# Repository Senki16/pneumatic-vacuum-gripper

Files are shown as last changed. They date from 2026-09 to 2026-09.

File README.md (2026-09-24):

# Pneumatic Vacuum Gripper for Robotic Arm

Modular vacuum gripper for the **CRP-RA09A-07** robotic arm, driven by a **FESTO VN-10-H** venturi generator with four Ø25 mm bellows suction cups in a cross layout. It handles flat parts up to **500 g** at an operating vacuum of **≥ −0.60 bar**, with real-time vacuum monitoring by an **ESP32** and an **MPX5700** sensor.

Final project (Phase 4) for *Mechanical Design – Methodical Design*, Department of Mechanical Engineering, **Universidad EAFIT** (Medellín, Colombia), May 2026.

<p align="center">
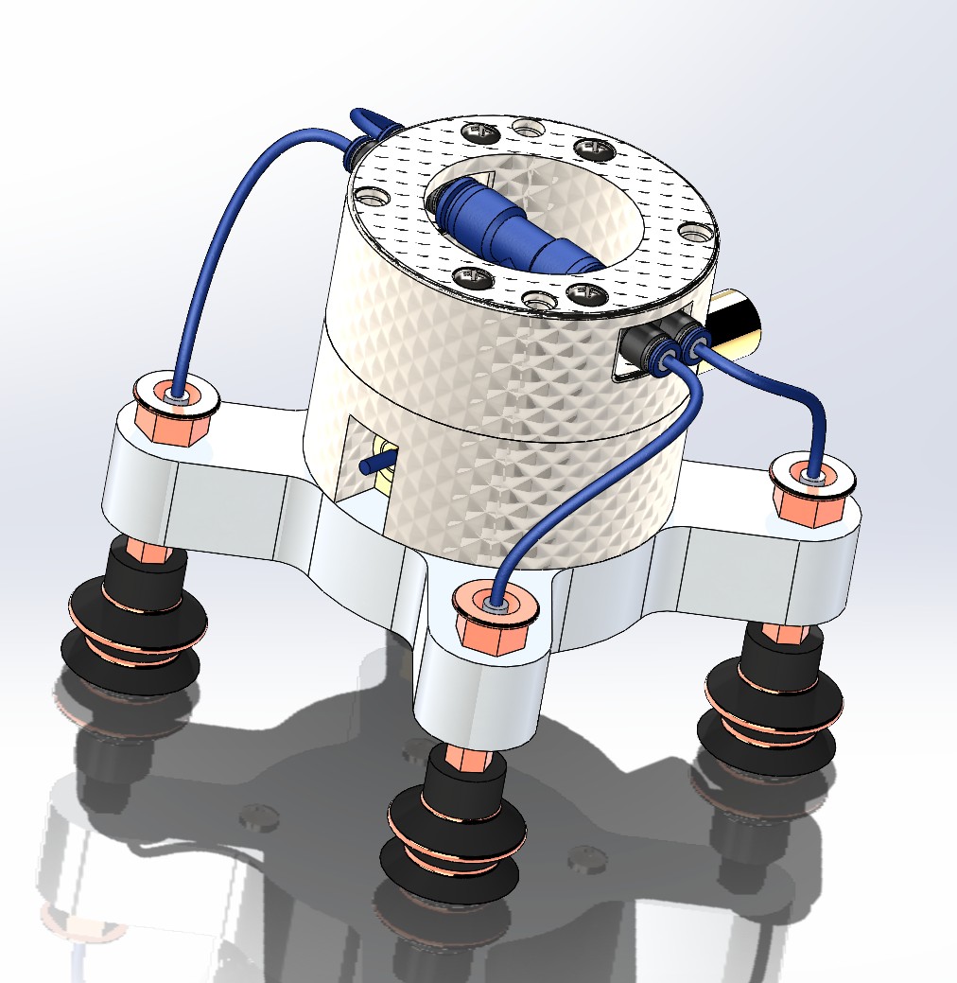
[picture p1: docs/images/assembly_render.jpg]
SolidWorks render of the pneumatic vacuum gripper assembly
  
</p>
<p align="center"><em>SolidWorks assembly: robot coupling, suction cup base, VN-10-H venturi and four Ø25 mm bellows suction cups.</em></p>

---

## Features

- **Structure:** three machined parts in 6061-T6 aluminum (suction cup base, upper coupling, robot coupling), ±0.1 mm tolerance, Ra 3.2 µm surface finish
- **Pneumatics:** FESTO VN-10-H venturi, 4–6 bar supply, 4 × Ø25 mm bellows suction cups, Ø6 mm tubing, T-connector and G1/8 fittings
- **Electronics:** ESP32, MPX5700 vacuum sensor, PNP vacuum switch set to −0.60 bar, LM2596 / AMS1117 regulators
- **Documentation:** 7 illustrated process charts (F1–F7) following ISO 9001:2015 clause 8.5.1, a QFD matrix, a validation plan and a cost analysis

## Test results

All six KPIs passed. Each was measured over at least 10 cycles.

| KPI | Target | Result |
|---|---|---|
| Grip force | ≥ 5 N | **6.2 N** ✅ |
| Positioning accuracy | ≤ 0.5 mm | **0.3 mm** ✅ |
| Repeatability (30 cycles at 5 bar) | ≥ 95 % | **96.7 %** ✅ |
| Response time | ≤ 0.5 s | **0.38 s** ✅ |
| Load capacity | 500 g for ≥ 30 s | **500 g for 36 s** ✅ |
| Operating vacuum | ≥ −0.60 bar | **−0.63 bar** ✅ |

The system also passed a leak test at 4 bar for 60 s with no bubbles.

## Cost

The best scenario (supplier C, using an existing air line) costs **$1,113,170 COP**. That is **34.6 % less** than the original baseline of $1,701,700 COP, with an estimated gross margin of 44.4 %. Details are in [`05_Spreadsheets/Costs`](05_Spreadsheets/Costs).

## Repository structure

```
01_CAD/
  SolidWorks_Assembly/      SolidWorks parts (.SLDPRT) and assemblies (.SLDASM)
  3D_Print_STL/             STL files ready for 3D printing
02_Documentation/           Final report (PDF) and design Q&A
03_Presentations/           PowerPoint and web (HTML) presentations
04_Process_Charts/          Illustrated manufacturing process charts F1–F7
05_Spreadsheets/            QFD, process chart, validation plan
  Costs/                    Cost and feasibility analysis
docs/images/                README images (assembly render)
_duplicates/                Duplicate copies kept for reference
```

## Manufacturing process charts

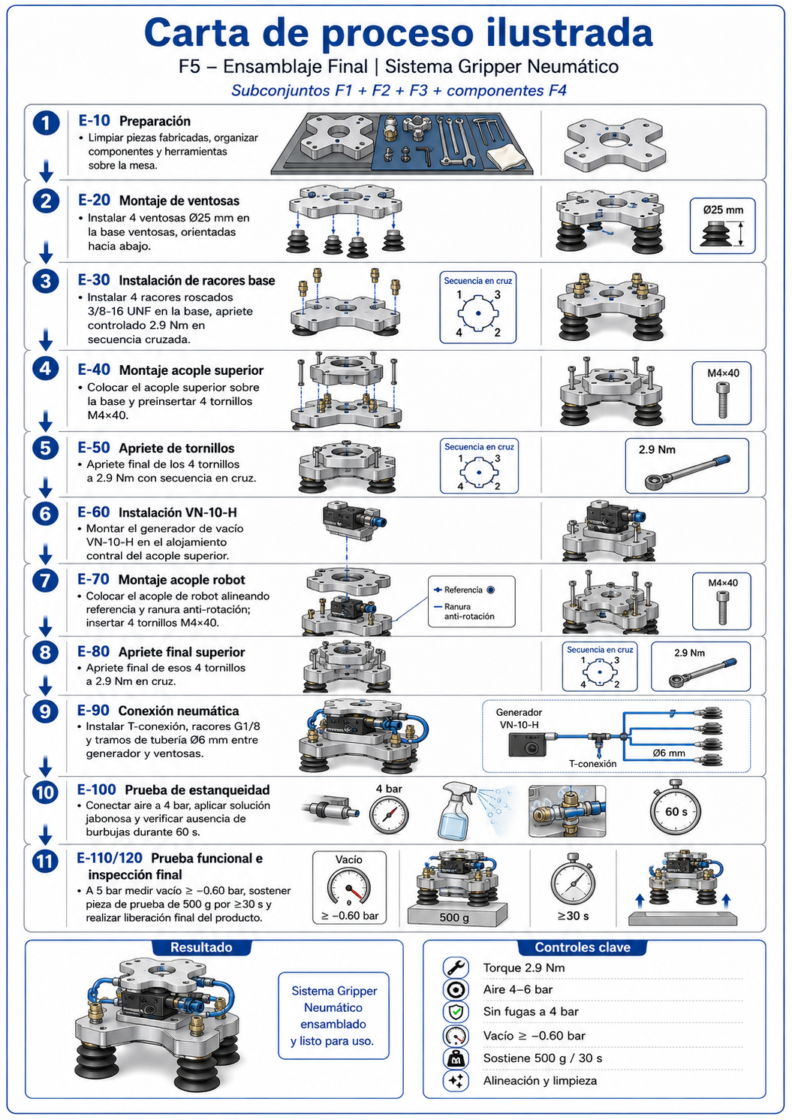
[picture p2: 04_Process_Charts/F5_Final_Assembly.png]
Final assembly process chart


| Chart | Part / stage | Setup (min) | Cycle (min) |
|---|---|---|---|
| [F1](04_Process_Charts/F1_Suction_Cup_Base.png) | Suction cup base – Al 6061-T6 | 90 | 210 |
| [F2](04_Process_Charts/F2_Upper_Coupling.png) | Upper coupling – Al 6061-T6 | 100 | 185 |
| [F3](04_Process_Charts/F3_Robot_Coupling.png) | Robot coupling – Al 6061-T6 | 85 | 145 |
| [F4](04_Process_Charts/F4_Commercial_Components.png) | Commercial components (receiving and prep) | — | — |
| [F5](04_Process_Charts/F5_Final_Assembly.png) | Final assembly and tests | 45 | 110 |
| [F6](04_Process_Charts/F6_Electrical_Assembly.html) | Electrical assembly | 75 | 125 |
| [F7](04_Process_Charts/F7_Pneumatic_Assembly.html) | Pneumatic assembly | — | — |
| | **Total** | **395** | **775** |

## Opening the CAD files

Open `01_CAD/SolidWorks_Assembly/Emsamblaje.SLDASM` in SolidWorks. Keep every part in the same folder so the assembly finds its references. The part files keep their original Spanish names so those references don't break.

## Team — Group 6

- Daniel Ruiz Sandoval
- David Zuluaga Henao
- Santiago Quintero Álvarez
- Julián Guerrero
- Ernesto Enríquez

**Professor:** Ronald Mauricio Martinod Restrepo

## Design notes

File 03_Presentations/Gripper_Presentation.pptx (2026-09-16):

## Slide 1

FASE 4

Prototipo Modelo Funcional
y Evaluación de Diseño

Sistema Gripper Neumático
para Brazo Robótico

Integrantes: Ruiz • Zuluaga • Quintero • Guerrero • Enríquez
Profesor: Ronald M. Martinod Restrepo
Universidad EAFIT — Grupo 6 | 8 de mayo de 2026

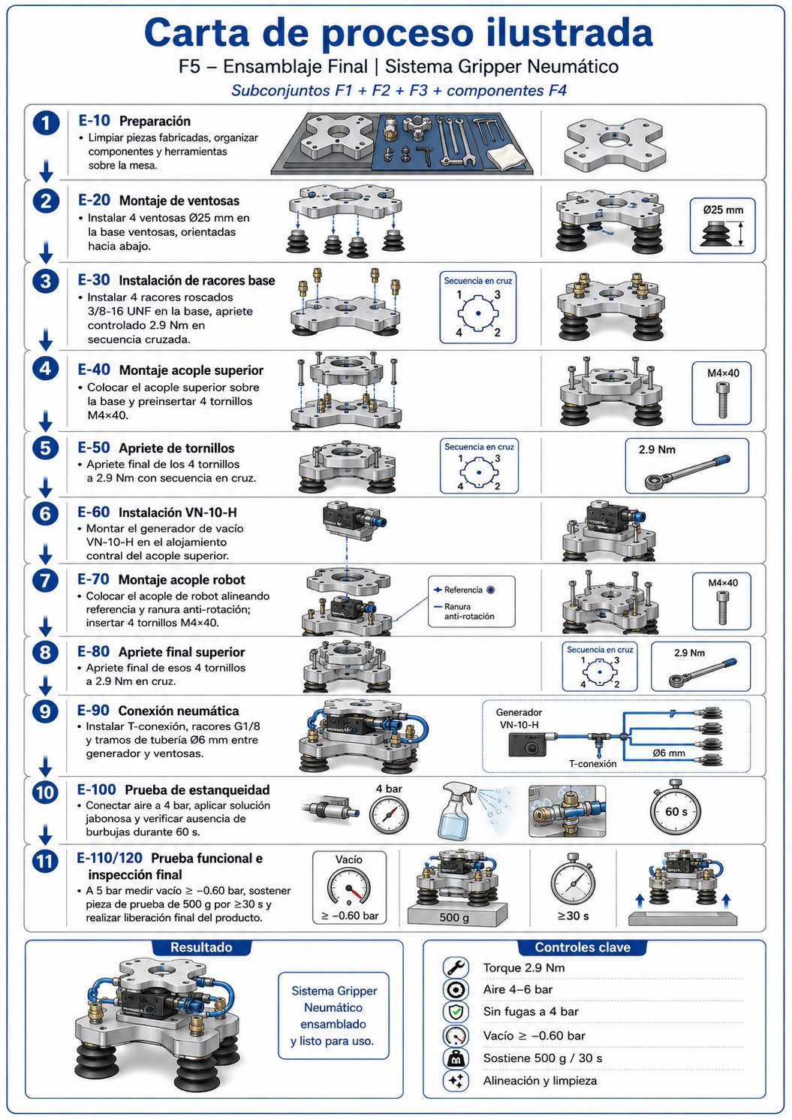
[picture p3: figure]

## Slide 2

Agenda

1. Introducción y Objetivos

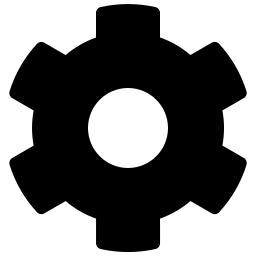
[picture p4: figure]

5. Matriz QFD — Componentes vs. Proceso

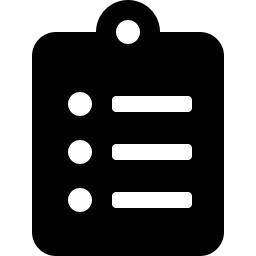
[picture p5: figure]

2. Cartas de Proceso de Fabricación (F1–F7)

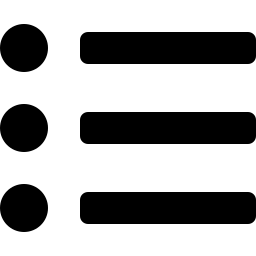
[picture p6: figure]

6. Análisis de Costos

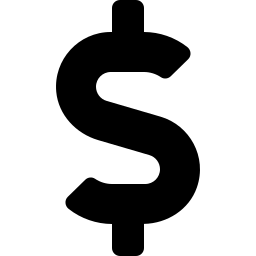
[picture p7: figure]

3. Desarrollo del Prototipo y Calibración

7. Viabilidad Económica

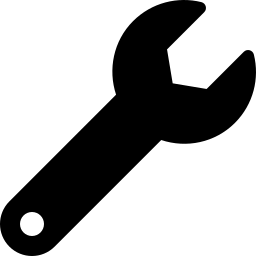
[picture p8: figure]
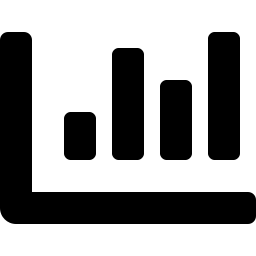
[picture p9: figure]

4. Indicadores de Evaluación y Plan de Pruebas

8. Conclusiones

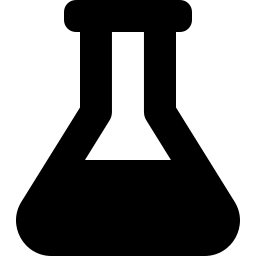
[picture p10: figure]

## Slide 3

01

Introducción
y Objetivos

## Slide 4

Introducción

Contexto
Los grippers son el elemento de interacción directa entre el robot y su entorno. Su diseño debe garantizar precisión, repetibilidad y eficiencia operativa.
Objetivo General
Desarrollar, ensamblar y validar un prototipo funcional de gripper neumático para brazo robótico, evaluando su viabilidad técnica y económica.
Objetivos Específicos
- Definir cartas de proceso de fabricación
- Construir el prototipo (tol. ±0,1 mm, Ra 3,2 µm)
- Ajustar y calibrar el sistema neumático
- Establecer KPIs y plan de pruebas
- Desarrollar matriz QFD
- Analizar costos y viabilidad económica

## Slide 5

02

Cartas de Proceso
de Fabricación F1–F7

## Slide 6

Resumen de Cartas de Proceso

F1

Base Ventosas

Setup / Ciclo:
90 / 210 min

F2

Acople Superior

Setup / Ciclo:
100 / 185 min

F3

Acople de Robot

Setup / Ciclo:
85 / 145 min

F4

Comp. Comerciales

Setup / Ciclo:
— / — min

F5

Ensamblaje Final

Setup / Ciclo:
— / — min

F6

Ensamble Eléctrico

Setup / Ciclo:
75 / 125 min

F7

Ensamble Neumático

Setup / Ciclo:
45 / 110 min

TOTAL: 395 min setup | 775 min ciclo | Norma: ISO 9001:2015 / ASME / DIN ISO 1711-1

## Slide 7

F1 — Base Ventosas

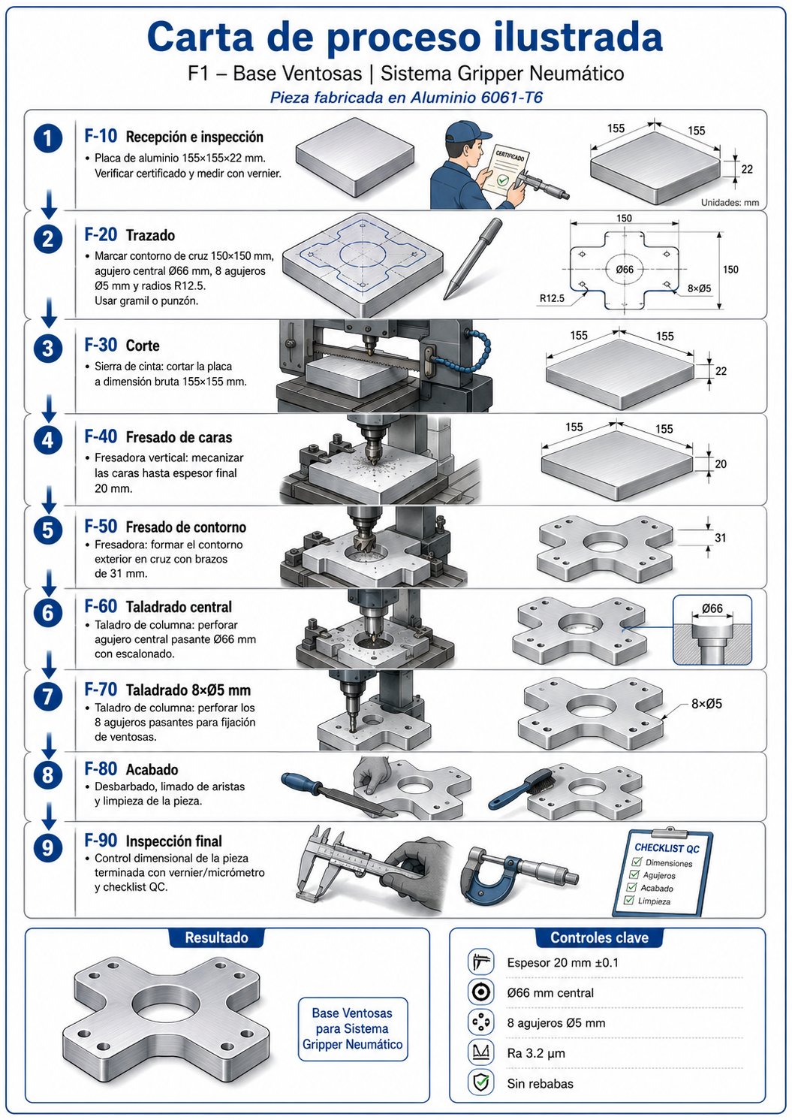
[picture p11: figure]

Al 6061-T6 | 150×150×20 mm | Ø66 central | 8×Ø5 | Ra 3,2 µm

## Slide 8

F2 — Acople Superior

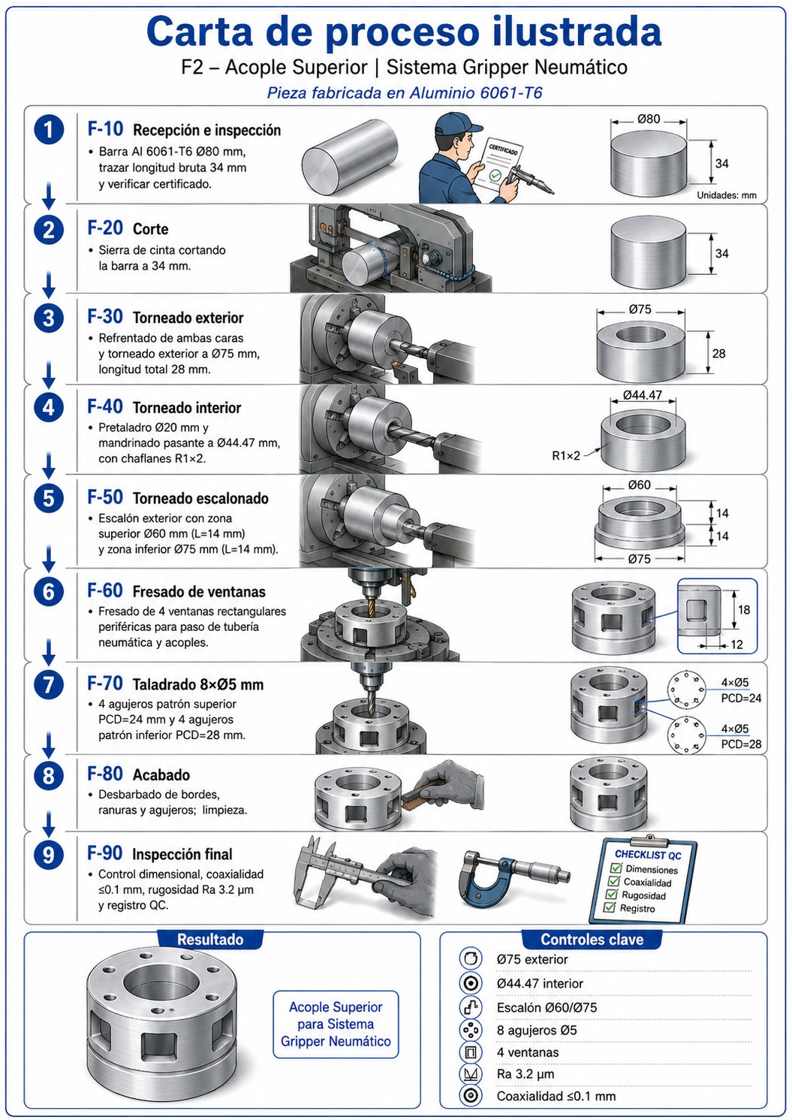
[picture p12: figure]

Al 6061-T6 | Ø75 ext. | Ø44,47 int. | L=28 mm | 8×Ø5

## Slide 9

F3 — Acople de Robot

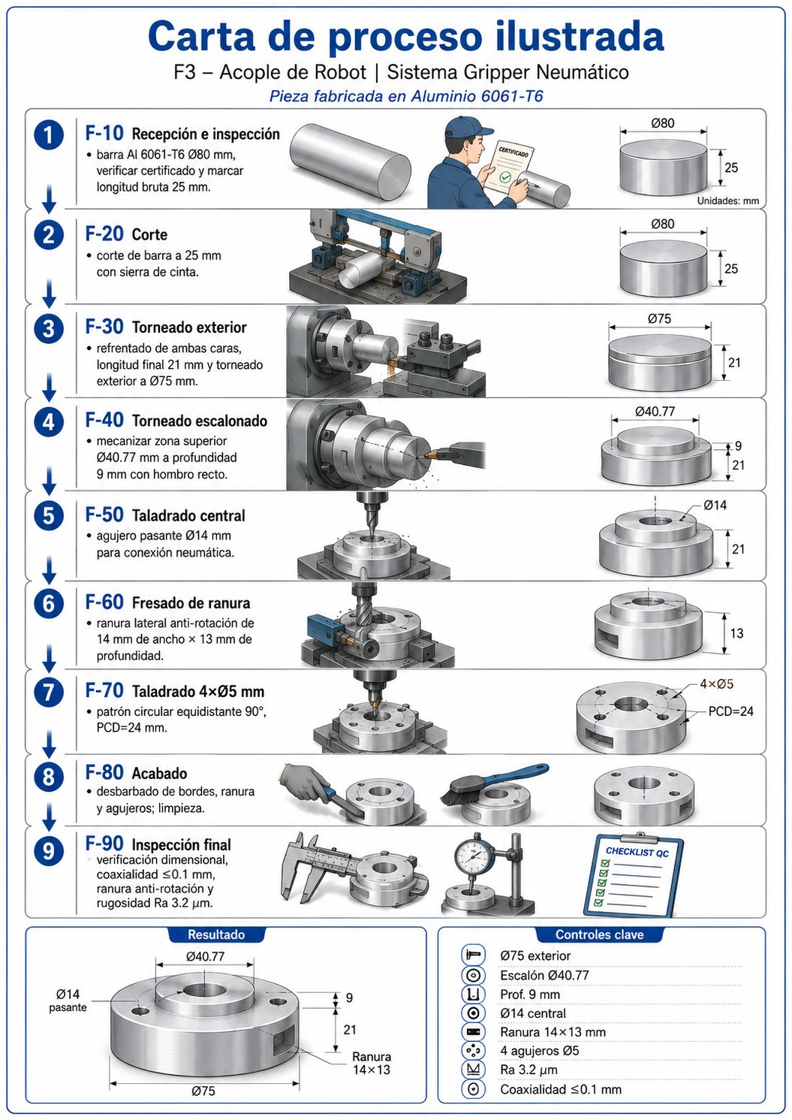
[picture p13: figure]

Al 6061-T6 | Ø75×21 mm | Escalón Ø40,77 | Ranura 14×13 mm

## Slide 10

F4 — Componentes Comerciales

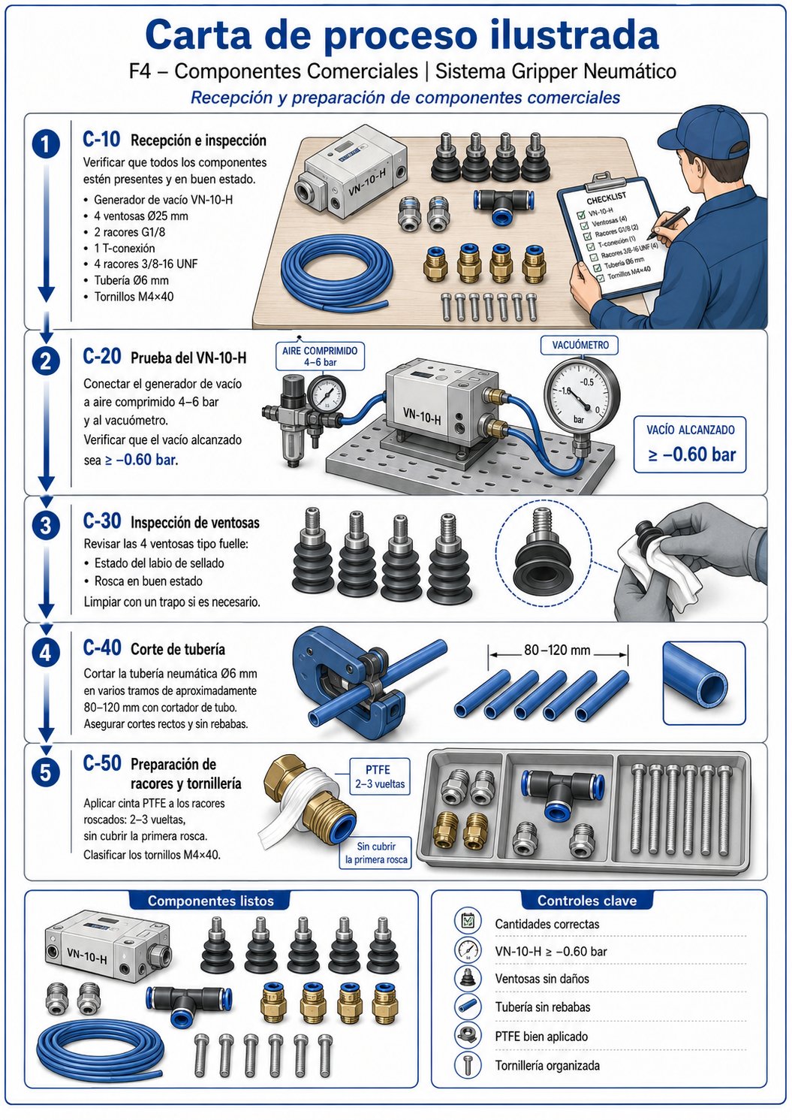
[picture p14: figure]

FESTO VN-10-H | 4× ventosas Ø25 | Cinta PTFE | Prueba vacío ≥ −0,60 bar

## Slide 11

F5 — Ensamblaje Final

Par 2,9 Nm secuencia cruzada | 4 bar/60 s estanqueidad | 500 g/30 s funcional

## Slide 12

F6 — Ensamble Eléctrico

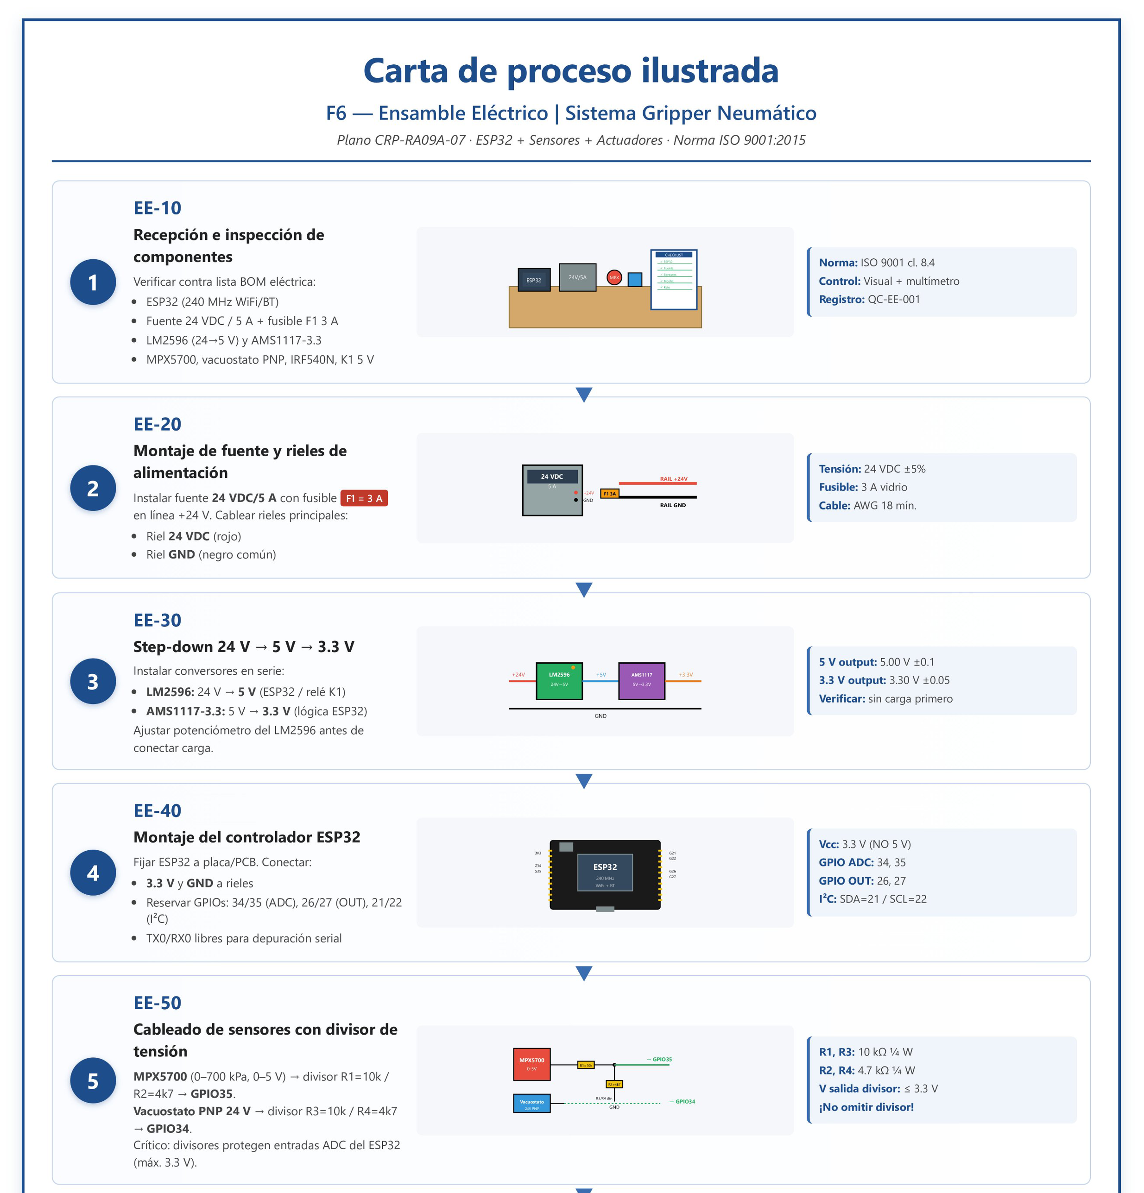
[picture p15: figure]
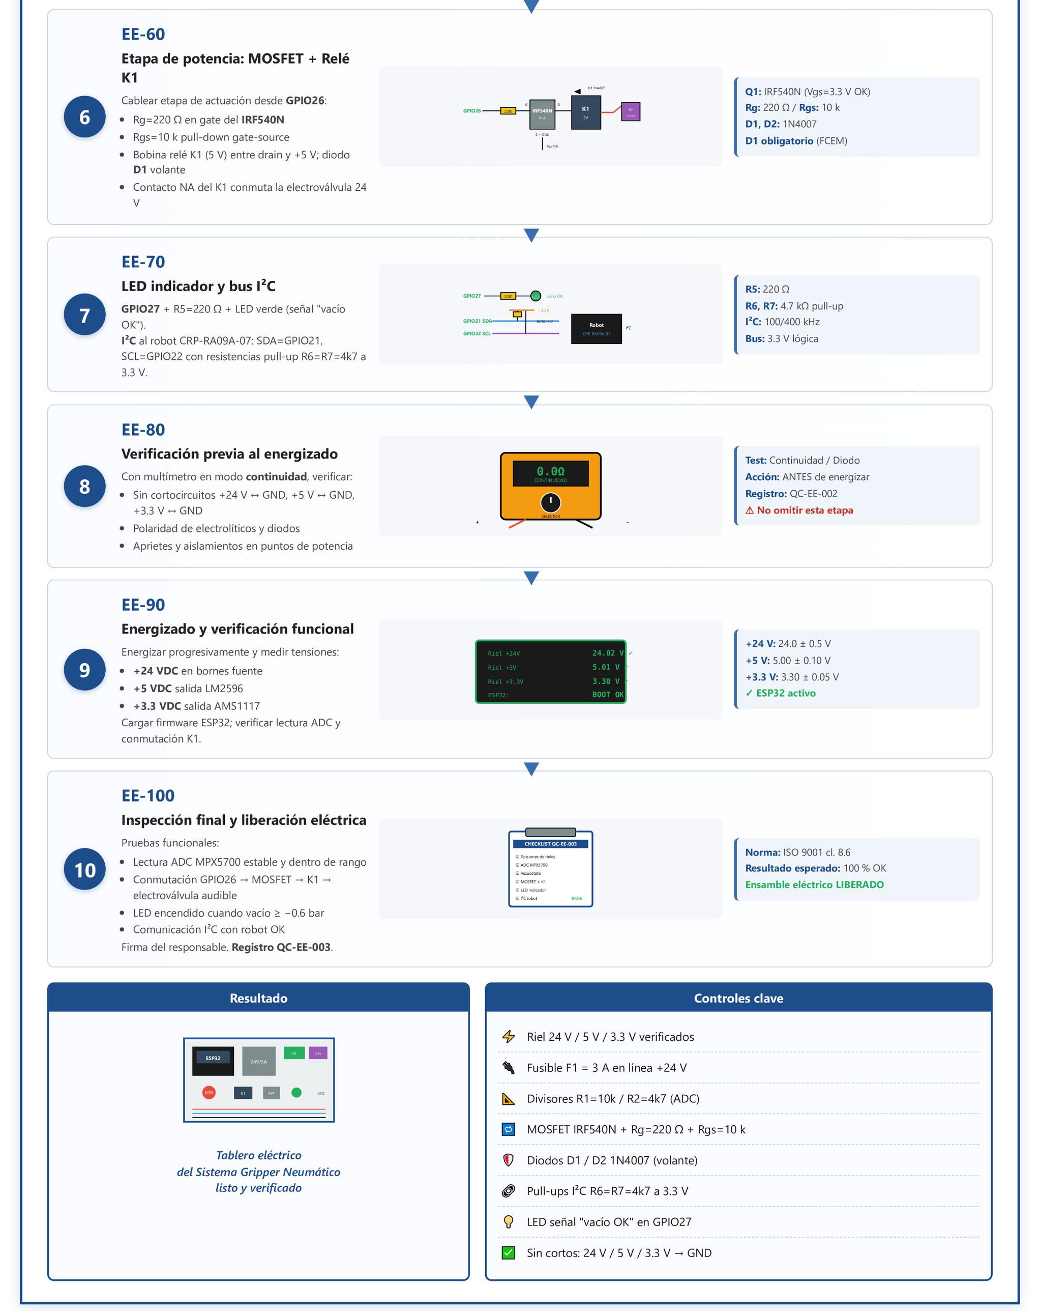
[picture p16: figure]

ESP32 | 24 VDC/5 A | LM2596 | AMS1117 | IRF540N | Relé K1 | Diodos 1N4007

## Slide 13

F7 — Ensamble Neumático

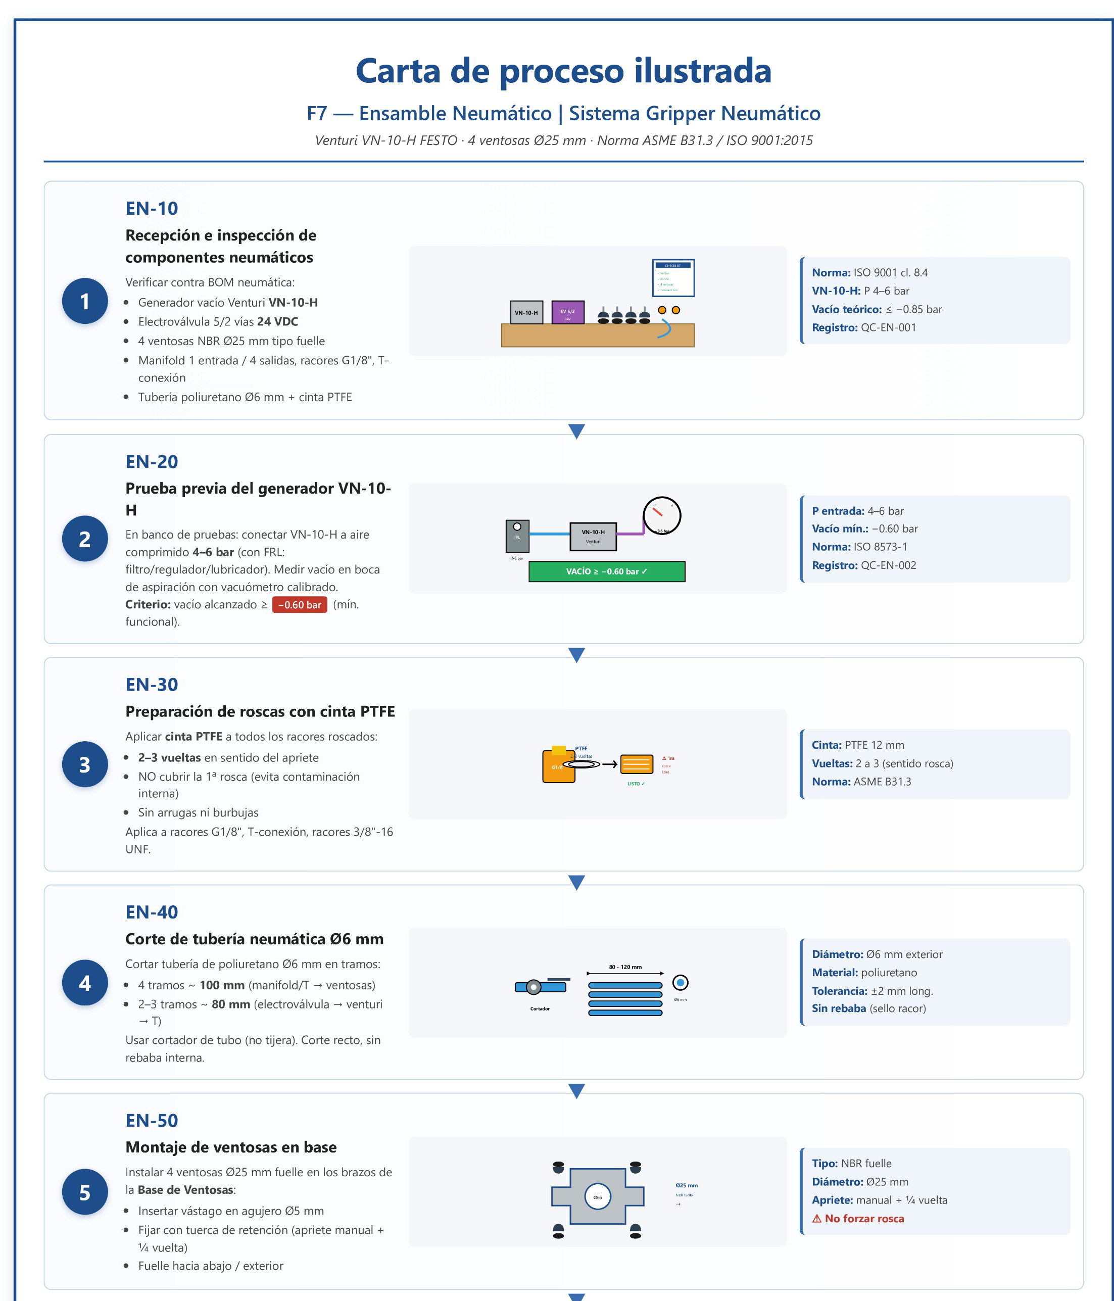
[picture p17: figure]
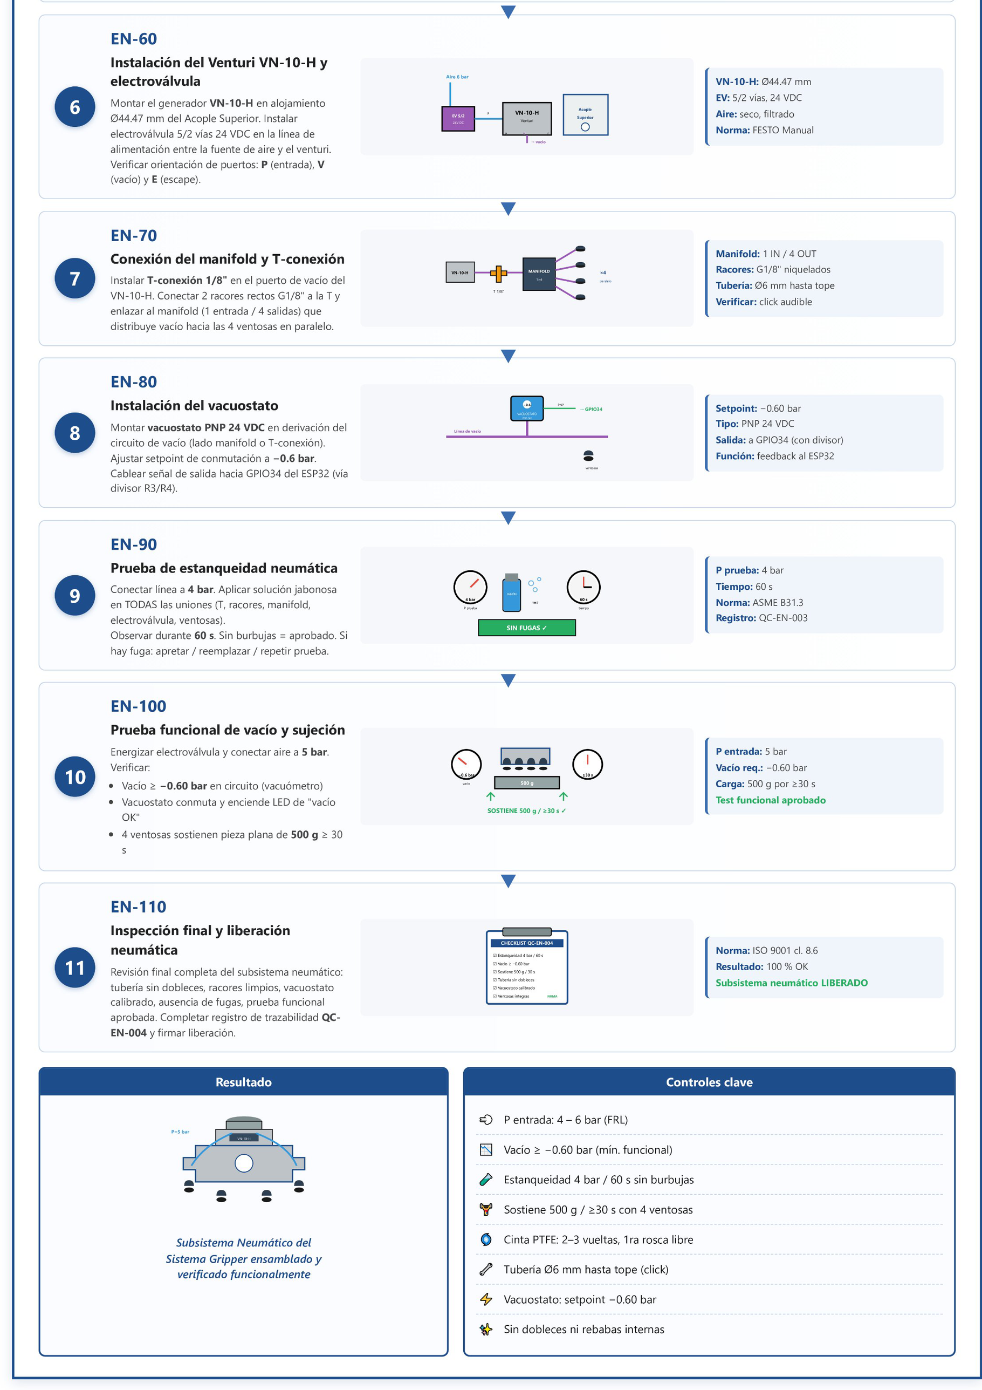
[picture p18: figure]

VN-10-H 4–6 bar | EV 5/2 | Manifold 1×4 | Vacuostato −0,60 bar | FRL

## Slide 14

03

Desarrollo del Prototipo
y Calibración

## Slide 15

Secuencia de Ensamblaje y Calibración

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
Fabricación
Al 6061-T6

QC Dimensional
100%

Prep.
Comerciales

Ensamble
Eléctrico

Ensamble
Neumático

Ensamble
Final

Estanqueidad
4 bar / 60 s

Prueba
Funcional

Torno + Fresadora
Taladro columna

Vernier · Micróm.
Comparador TIR

PTFE + Prueba
VN-10-H ≥−0,60 bar

LM2596→5V
AMS1117→3,3V

Manifold + EV
Vacuostato −0,60

2,9 Nm cruz
1→3→2→4

Sin burbujas
QC-E-003

500 g · 30 s
Vacío ≥−0,60 bar

Neumática

VN-10-H 4–6 bar → vacío ≥ −0,60 bar

Vacuostato

Setpoint −0,60 bar → GPIO34 vía divisor

Par tornillos

2,9 Nm DIN ISO 1711-1 → secuencia cruzada

ADC ESP32

MPX5700 con divisor 10 kΩ / 4,7 kΩ → ≤ 3,3 V

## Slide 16

04

Indicadores de Evaluación
y Plan de Pruebas

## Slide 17

KPIs y Plan de Pruebas del Gripper

Fuerza de agarre

≥ 5 N

MPX5700 + dinamómetro

Precisión posic.

≤ 0,5 mm

Comparador / regla

Repetibilidad

≥ 95% éxito

30 ciclos sucesivos

Tiempo respuesta

≤ 0,5 s

Cronómetro / oscilosc.

Capacidad de carga

≥ 500 g / 30 s

Pieza patrón + cronóm.

Vacío de operación

≥ −0,60 bar

Vacuómetro calibrado

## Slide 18

05

Matriz QFD
Componentes vs. Proceso

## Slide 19

Casa de la Calidad — QFD

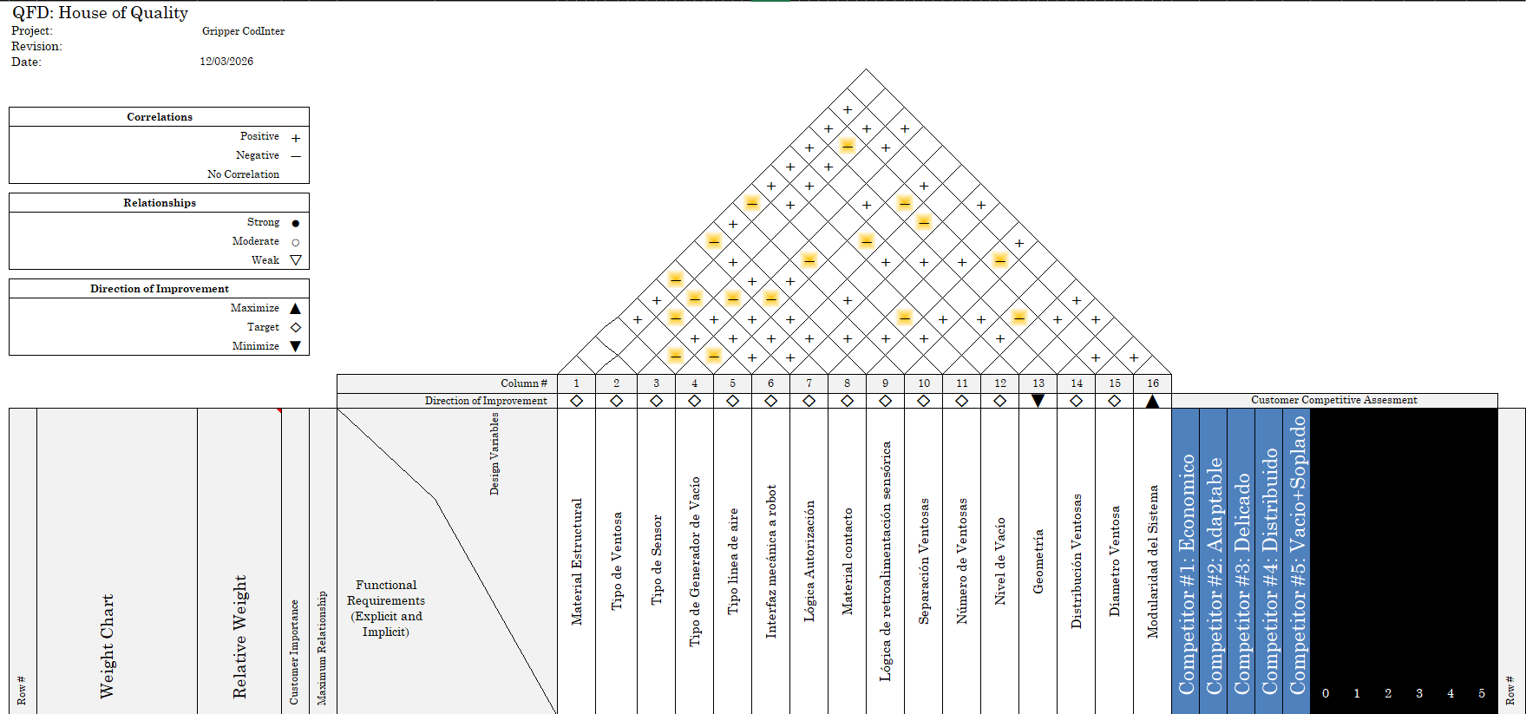
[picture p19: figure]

16 componentes × 16 variables | Relaciones: Fuerte ● Moderada ○ Débil ▽

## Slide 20

Matriz QFD — Requisitos Funcionales vs. Variables

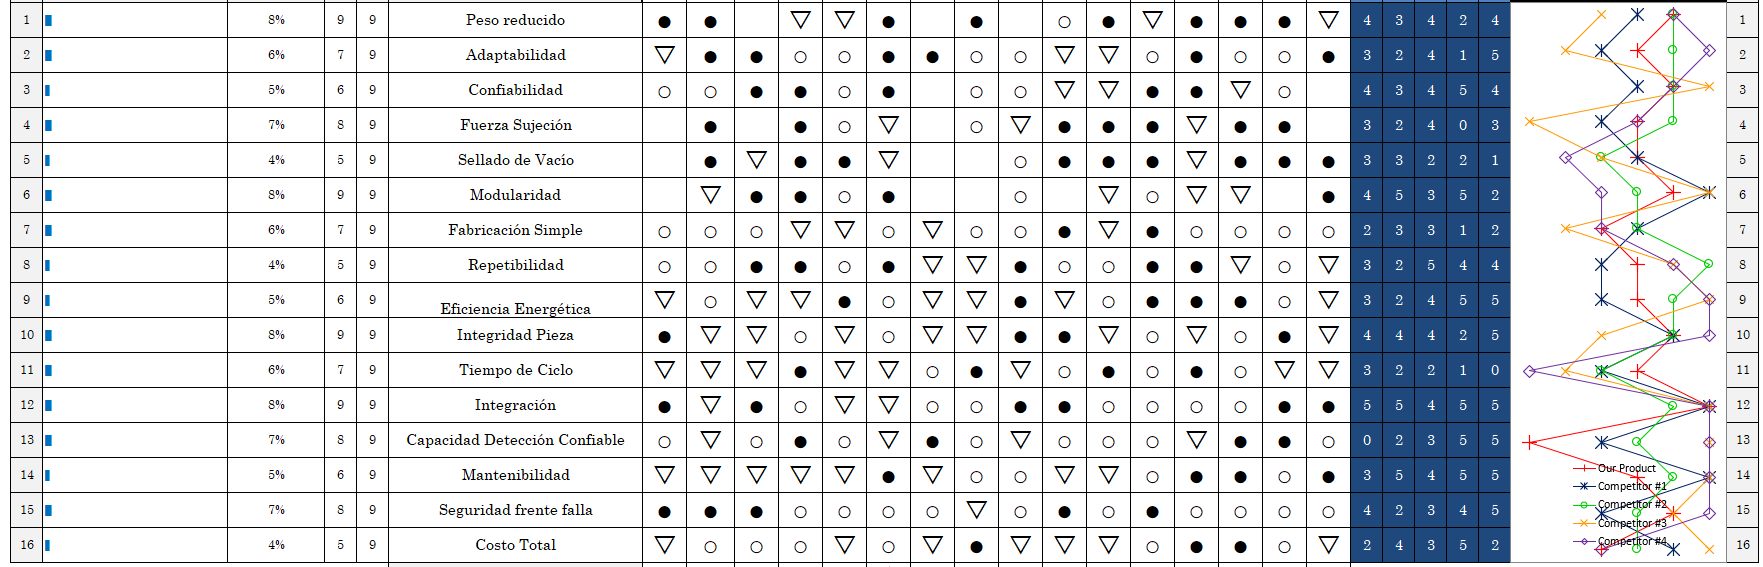
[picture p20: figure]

Comparación con 5 competidores | Mayor impacto: Validación 8,2% · Ciclo de vida 8,0% · Fiabilidad 7,7%

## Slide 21

QFD — Importancia Técnica Relativa

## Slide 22

06

Análisis de Costos

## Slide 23

Distribución de Costos — Prototipo vs. Industrial

Prototipo

$1.701.700

Industrial

$1.726.700

P. Venta Proto

$3.063.060

Margen

44,4%

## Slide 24

Costos Prototipo — Detalle por Ítem

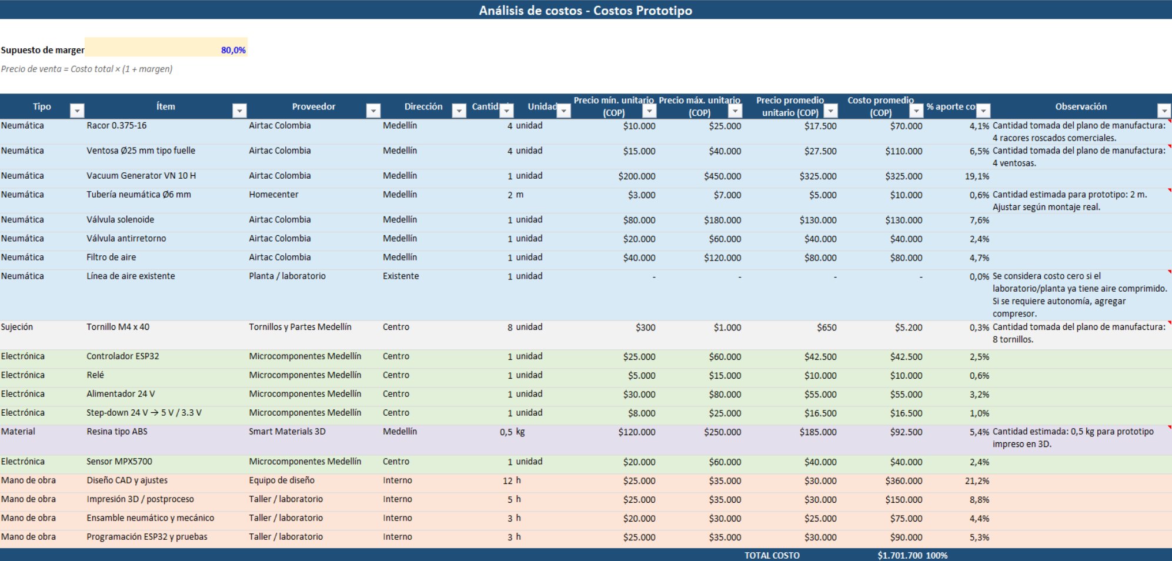
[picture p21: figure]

VN-10-H 19,1% · Mano de obra CAD 21,2% · Total $1.701.700 COP

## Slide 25

Costos Industrial — Detalle por Ítem

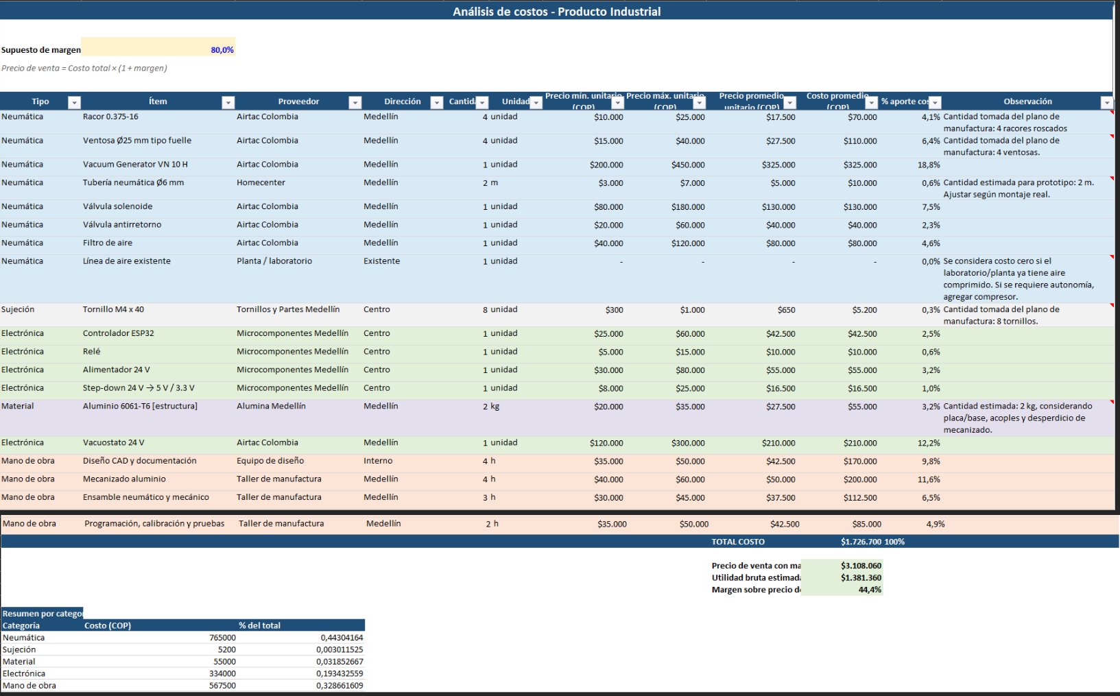
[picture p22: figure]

Vacuostato 24V 12,2% · Aluminio estructura 3,2% · Total $1.726.700 COP

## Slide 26

07

Evaluación de
Viabilidad Económica

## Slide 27

Comparación Económica y Viabilidad

Diferencia costo

$25.000 COP
(+1,5%)

Margen s/ precio

44,4%
ambos escenarios

Precio mín. proto

$3.063.060

Precio mín. ind.

$3.108.060

Margen 80% | Línea de aire existente (costo $0)

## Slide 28

08

Conclusiones

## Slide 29

Conclusiones

Prototipo funcional validado con vacío ≥ −0,60 bar y sujeción de 500 g por ≥ 30 s

7 cartas de proceso documentadas bajo ISO 9001:2015 — 395 min setup / 775 min ciclo

Costo prototipo: $1.701.700 COP | Precio de venta recomendado: $3.063.060 COP (80% margen)

Producto industrial solo 1,5% más costoso ($1.726.700) con mayor confiabilidad

QFD identifica Validación (8,2%) y Ciclo de vida (8,0%) como las variables más críticas

Par 2,9 Nm en secuencia cruzada + estanqueidad 4 bar/60 s garantizan la integridad mecánica

Universidad EAFIT · Diseño Metódico — Grupo 6 · Mayo 2026

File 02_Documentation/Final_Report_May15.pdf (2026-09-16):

Universidad EAFIT — Diseño Metódico — Sistema Gripper Neumático — Fase 4 | Grupo 6 | Mayo 2026

# Sistema Gripper Neumático de Vacío para Brazo Robótico

## Fase 4 — Prototipo Funcional · Evaluación de Diseño · Análisis de Costos Integrado (v3)

Daniel Ruiz Sandoval · David Zuluaga Henao · Santiago Quintero Álvarez · Julián Guerrero · Ernesto Enríquez Departamento de Ingeniería Mecánica — Universidad EAFIT, Medellín, Colombia

Diseño Mecánico – Diseño Metódico | Grupo 6 | Prof. Ronald Mauricio Martinod Restrepo | Mayo 2026

Abstract — Se documenta el desarrollo completo del prototipo funcional de un gripper neumático de vacío modular accionado por venturi FESTO VN-10-H, con cuatro ventosas de fuelle ∅25 mm en distribución en cruz, capaz de manipular piezas planas de hasta 500 g con vacío operacional ≥ −0,60 bar durante ≥ 30 s. Se presentan: (i) las siete cartas de proceso ilustradas F1–F7 con sus tablas de operaciones; (ii) indicadores de desempeño cuantificables; (iii) la matriz QFD con pesos relativos; (iv) plan de pruebas de validación; y (v) un análisis de costos integrado y optimizado que cruza tres fuentes de precios, identifica los ítems de mayor ahorro potencial y evalúa cuatro escenarios económicos. El escenario óptimo (Fuente C, línea de aire existente) alcanza $1.113.170 COP, una reducción de 34,6 % respecto al modelo base original de $1.701.700 COP, manteniendo todas las prestaciones técnicas requeridas y un margen bruto estimado del 44,4 % sobre precio de venta.
Palabras clave — gripper neumático; vacío venturi; FESTO VN-10-H; aluminio 6061-T6; ESP32; QFD; análisis de costos; cartas de proceso; ISO 9001:2015; ingeniería de valor.

### 1. INTRODUCCIÓN

El diseño de sistemas de sujeción robóticos (grippers) es un elemento crítico en la automatización industrial moderna. Un gripper bien diseñado determina la precisión, la cadencia y la seguridad de toda la célula robótica. En este contexto, la Fase 4 del proyecto documenta la transición del diseño conceptual al prototipo físico validado, cerrando el ciclo de diseño metódico iniciado en fases anteriores.
El sistema desarrollado es un gripper de vacío modular accionado por el generador venturi FESTO VN-10-H, con cuatro ventosas de fuelle ∅25 mm en distribución simétrica en cruz, controlado por un microcontrolador ESP32 que monitorea en tiempo real el nivel de vacío mediante el sensor MPX5700 y un vacuostato PNP con setpoint configurable en −0,60 bar. Las tres piezas estructurales (Base Ventosas, Acople Superior y Acople de Robot) están mecanizadas en aluminio 6061-T6 con tolerancias ±0,1 mm y rugosidad Ra 3,2 µm en superficies funcionales, siguiendo los estándares documentales de ISO 9001:2015.

Esta versión mejorada del informe incorpora: (a) análisis de costos enriquecido con tres fuentes de precios reales y cuatro escenarios económicos comparados; (b) gráficas de distribución y comparación de costos generadas a partir de los datos tabulados;
(c) profundización en el análisis de viabilidad económica con indicadores de ingeniería de valor; y (d) conclusiones técnicas y económicas integradas por sección.

### 2. OBJETIVOS

Objetivo general. Desarrollar, ensamblar y validar un prototipo funcional de gripper neumático para brazo robótico CRP-RA09A-07, mediante procesos de manufactura documentados bajo ISO 9001:2015, pruebas experimentales controladas y análisis técnico-económico integrado con optimización de costos, determinando la viabilidad del sistema para aplicaciones preindustriales.

Objetivos específicos: (1) Definir y documentar las cartas de proceso F1–F7 con tiempos de setup y ciclo. (2) Fabricar el prototipo respetando tolerancias ±0,1 mm y Ra 3,2 µm. (3) Calibrar el sistema neumático para alcanzar vacío ≥ −0,60 bar a 5 bar de entrada.
(4) Establecer seis KPIs cuantificables con criterios de aceptación binarios. (5) Construir la Matriz QFD con 16 componentes y 16 procesos/variables. (6) Diseñar y ejecutar un plan de 7 pruebas de validación. (7) Analizar costos con tres fuentes de precios reales e identificar el escenario óptimo.

### 3. CARTAS DE PROCESO DE FABRICACIÓN

El proceso productivo se estructura en siete cartas de proceso ilustradas (F1–F7), siguiendo la cláusula 8.5.1 de ISO 9001:2015 (Control de la producción y de la prestación del servicio). Cada carta define la secuencia de operaciones, los parámetros de proceso (velocidad de corte, par de apriete, presión de prueba), los instrumentos de control de calidad y los tiempos de setup y ciclo. El tiempo total estimado es 395 min de setup y 775 min de ciclo, distribuidos según la Tabla I.

C ar ta | Componente / Subconjunto | Proceso | Setup (min) | Ciclo (min) | Registro QC
F1 | Base Ventosas GN-001 – Al 6061-T6 | Mecanizado conv. | 90 | 210 | QC-F-001
F2 | Acople Superior GN-002 – Al 6061-T6 | Mecanizado conv. | 100 | 185 | QC-F-002
F3 | Acople de Robot GN-003 – Al 6061-T6 | Mecanizado conv. | 85 | 145 | QC-F-003
F4 | Componentes Comerciales GN-F4-001 | Recepción / prep. | — | — | QC-C-001
F5 | Ensamblaje Final GN-F5-001 | Ensamble + pruebas | 45 | 110 | QC-E-001–005
F6 | Ensamble Eléctrico GN-EE-001 | Ensamble + pruebas | 75 | 125 | QC-EE-001–003
F7 | Ensamble Neumático GN-EN-001 | Ensamble + pruebas | — | — | QC-EN-001–004
| <b>TOTAL</b> | <b>395</b><b>775</b>21 registros
TABLA I. Resumen de cartas de proceso — Sistema Gripper Neumático.

A. F1 – Base Ventosas (Al 6061-T6)
Pieza estructural inferior fabricada a partir de placa Al 6061-T6 (155×155×22 mm). Dimensiones finales: 150×150 mm, espesor 20 mm, contorno en cruz con brazos de 31 mm, agujero central escalonado ∅66 mm y 8 agujeros pasantes ∅5 mm para fijación de ventosas. La secuencia de 9 operaciones incluye corte con sierra de cinta, fresado de caras y de contorno en fresadora vertical, taladrado en columna y control dimensional 100 % con vernier, micrómetro y checklist QC-F-001.

Controles clave F1: Espesor 20 mm ±0,1 mm · ∅66 mm central · 8 agujeros ∅5 mm · Ra 3,2 µm · Sin rebabas.


Fig. 1. Carta de proceso ilustrada F1 – Base Ventosas (Al 6061-T6).

Op. | Etapa | Descripción | Setup | Ciclo
F-10 | Recepción | Placa Al 155×155×22 mm, verificar cert., medir con vernier | 5 | 10
F-20 | Trazado | Cruz 150×150, ∅66, 8×∅5, R12,5 con gramil/punzón | 5 | 15
F-30 | Corte | Sierra de cinta a dimensión bruta 155×155 mm | 10 | 15
F-40 | Fresado caras | Fresadora vertical → espesor final 20 mm (Ra 3,2 µm) | 15 | 25
F-50 | Fresado contornoContorno en cruz, brazos 31 mm, redondeos R12,5 | | 20 | 50
F-60 | Taladrado ∅66 | Agujero central pasante escalonado ∅10→∅66 mm | 15 | 30
F-70 | Taladrado 8×∅5 8 agujeros pasantes ∅5 mm para fijación ventosas | | 10 | 25
F-80 | Acabado | Desbarbado, lima fina, papel P120/P240 | 5 | 20
F-90 | Inspección | Control dimensional 100 %, coaxialidad, registro QC-F-001 | 5 | 20
<b>Totales</b> | <b>90</b><b>210</b>
TABLA II. Operaciones F1 – Base Ventosas.

B. F2 – Acople Superior (Al 6061-T6)
Pieza intermedia que aloja el generador de vacío VN-10-H y enlaza la Base Ventosas con el Acople de Robot. Fabricada desde barra Al ∅80 mm. Dimensiones finales: ∅75 mm exterior, ∅44,47 mm interior pasante, longitud 28 mm, escalón exterior ∅60 mm (L=14 mm) / ∅75 mm (L=14 mm), 4 ventanas rectangulares periféricas 18×12 mm para paso de tubería y 8 agujeros ∅5 mm (PCD 24 y PCD 28). La coaxialidad entre ∅44,47 y ∅75 debe ser ≤ 0,1 mm TIR (verificada con reloj comparador, registro QC-F-002).

Tolerancia crítica F2: Coaxialidad ∅44,47 vs ∅75 ≤ 0,1 mm TIR — valor excedido genera fuga de vacío por deformación asimétrica del sello del VN-10-H.


Fig. 2. Carta de proceso ilustrada F2 – Acople Superior (Al 6061-T6).

Op. | Etapa | Descripción | Setup | Ciclo
F-10 | Recepción | Barra Al ∅80 mm, verificar cert., longitud bruta 34 mm | 5 | 8
F-20 | Corte | Sierra de cinta a 34 mm | 5 | 10
F-30 | Torneado ext. | Refrentado ambas caras, exterior ∅75 mm, L=28 mm | 15 | 20
F-40 | Torneado int. | Pretaladro ∅20 mm y mandrinado ∅44,47 mm, chaflanes R1×2 | 15 | 25
F-50 | Torneado esc. | Escalón exterior ∅60 (L=14) / ∅75 (L=14) | 15 | 30
F-60 | Fresado vent. | 4 ventanas rectangulares periféricas 18×12 mm | 20 | 35
F-70 | Taladrado | 4×∅5 PCD 24 + 4×∅5 PCD 28 | 15 | 25
F-80 | Acabado | Desbarbado, lima de aguja, avellanador 90° | 5 | 12
F-90 | Inspección | Coaxialidad TIR ≤ 0,1 mm, Ra 3,2 µm, QC-F-002 | 5 | 20
<b>Totales</b> | <b>100</b> <b>185</b>
TABLA III. Operaciones F2 – Acople Superior.

C. F3 – Acople de Robot (Al 6061-T6)
Interfaz mecánica con el brazo robótico CRP-RA09A-07. Fabricada desde barra Al ∅80 mm. Dimensiones finales: ∅75 mm exterior, longitud 21 mm, escalón superior ∅40,77 mm a profundidad 9 mm con hombro recto (para asiento en el flange del robot), agujero central pasante ∅14 mm (conducción neumática interna) y ranura lateral anti-rotación 14×13 mm. El patrón de 4 agujeros ∅5 mm PCD=24 mm equidistantes 90° garantiza la alineación repetible con la referencia del robot.

Nota de integración F3: La ranura anti-rotación 14×13 mm es crítica — sin ella, el par de apriete de los tornillos M4×40 generaría rotación del acople durante el ensamble, desalineando el eje neumático central con el puerto del robot.


Fig. 3. Carta de proceso ilustrada F3 – Acople de Robot (Al 6061-T6).

Op. | Etapa | Descripción | Setup | Ciclo
F-10 | Recepción | Barra Al ∅80 mm, verificar cert., marcar longitud bruta 25 mm | 5 | 8
F-20 | Corte | Sierra de cinta a 25 mm | 5 | 10
F-30 | Torneado ext. | Refrentado ambas caras, exterior ∅75 mm, L=21 mm | 15 | 20
F-40 | Torneado esc. | Escalón ∅40,77 a 9 mm de profundidad con hombro recto | 15 | 25
F-50 | Taladrado ∅14 | Agujero central pasante ∅14 mm para conexión neumática | 10 | 15
F-60 | Fresado ranura | Ranura anti-rotación lateral 14×13 mm | 15 | 25
F-70 | Taladrado 4×∅5 Patrón circular equidistante 90°, PCD=24 mm | | 10 | 15
F-80 | Acabado | Desbarbado de bordes, ranura y agujeros; limpieza | 5 | 12
F-90 | Inspección | Coaxialidad TIR ≤ 0,1 mm, ranura anti-rotación, QC-F-003 | 5 | 15
<b>Totales</b> | <b>85</b><b>145</b>
TABLA IV. Operaciones F3 – Acople de Robot.

D. F4 – Componentes Comerciales
Esta carta documenta la recepción, inspección y preparación de todos los componentes adquiridos: generador de vacío FESTO VN-10-H, 4 ventosas de fuelle ∅25 mm NBR/silicona, racores G1/8" y 3/8"-16 UNF, T-conexión, tubería poliuretano ∅6 mm, tornillos M4×40 ISO 7045 clase 8.8. La prueba funcional del VN-10-H a 4–6 bar debe confirmar vacío ≥ −0,60 bar antes de autorizar el ensamble.

Control crítico C-20: Si el VN-10-H no alcanza −0,60 bar en banco de pruebas, la unidad debe ser devuelta al proveedor — no proceder al ensamble con unidad defectuosa.

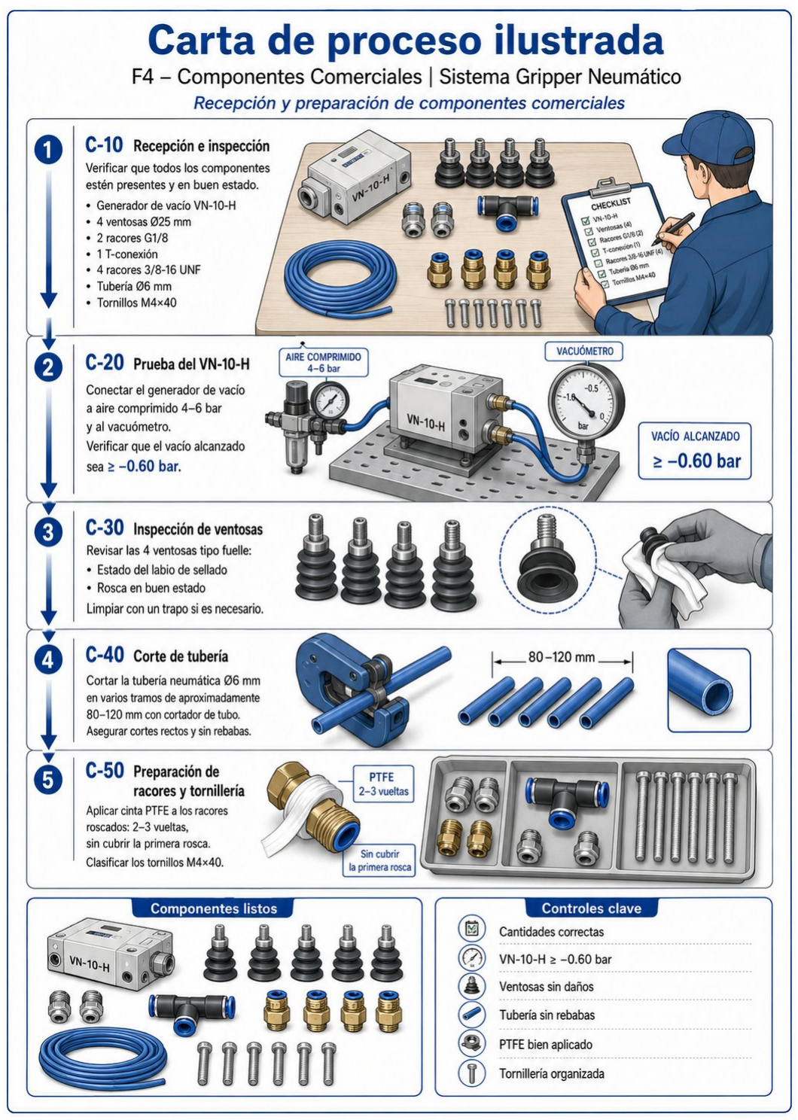
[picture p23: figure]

Fig. 4. Carta de proceso ilustrada F4 – Componentes Comerciales.

Op. | Etapa | Descripción
C-10 | Recepción | Verificación de referencias, cantidades y certificados. Registro QC-C-001.
C-20 | Prueba VN-10-H | Banco 4–6 bar + vacuómetro; criterio: vacío ≥ −0,60 bar.
C-30 | Inspección ventosasLabio de sellado y rosca sin daños; limpieza con trapo si necesario.
C-40 | Corte tubería | Cortes perpendiculares 80–120 mm con cortador de tubo; sin rebaba interna.
C-50 | Preparación roscasCinta PTFE 2–3 vueltas en racores; NO cubrir primera rosca.
TABLA V. Operaciones F4 – Componentes Comerciales.

E. F5 – Ensamblaje Final
Integra los subconjuntos F1+F2+F3 con los componentes preparados en F4. El procedimiento de 12 operaciones incluye: montaje de ventosas con fuelle hacia abajo, instalación de racores 3/8"-16 UNF a par controlado 2,9 Nm en secuencia cruzada (1→3→2→4 según DIN ISO 1711-1), montaje del Acople Superior con 4 tornillos M4×40, instalación del VN-10-H, montaje del Acople de Robot alineando ranura anti-rotación, conexión neumática con T-conexión y tubería ∅6 mm. Las pruebas finales incluyen estanqueidad (4 bar/60 s) y funcional (5 bar, 500 g, ≥30 s).

Secuencia cruzada de apriete: Orden 1→3→2→4 a 2,9 Nm garantiza distribución uniforme de carga y planitud de la junta; el apriete lineal genera alabeo que compromete el sellado neumático. Registrado en QC-E-001 y QC-E-002.


Fig. 5. Carta de proceso ilustrada F5 – Ensamblaje Final.

Op. | Etapa | Descripción
E-10 | Preparación | Limpieza con alcohol isopropílico; organizar componentes y herramientas.
E-20 | Montaje ventosas | 4 ventosas ∅25 mm en brazos de la base, fuelle orientado hacia abajo.
E-30 | Racores base | 4 racores 3/8"-16 UNF, par 2,9 Nm en secuencia cruzada. QC-E-001.
E-40 | Acople Superior | Posicionar sobre la base; pre-insertar 4 tornillos M4×40 a mano.

Op. | Etapa | Descripción
E-50 | Apriete tornillería | Par final 2,9 Nm en secuencia 1→3→2→4. QC-E-001.
E-60 | Instalación VN-10-HInserción suave en alojamiento ∅44,47 mm del Acople Superior.
E-70 | Acople Robot | Alinear referencia + ranura anti-rotación; insertar 4 tornillos M4×40.
E-80 | Apriete final | Par 2,9 Nm en secuencia cruzada. QC-E-002.
E-90 | Conexión neumáticaT-conexión + racores G1/8" + tubería ∅6 mm generador→ventosas.
E-100 | Prueba estanqueidad4 bar / 60 s con solución jabonosa; criterio: sin burbujas. QC-E-003.
E-110 | Prueba vacío | 5 bar: medir vacío ≥ −0,60 bar; sostener 500 g por ≥ 30 s. QC-E-004.
E-120 | Inspección final | Liberación del producto. QC-E-005.
TABLA VI. Operaciones F5 – Ensamblaje Final.

F. F6 – Ensamble Eléctrico (ESP32 + Sensores + Actuadores)
El subsistema eléctrico centraliza el monitoreo y control del vacío mediante un microcontrolador ESP32 (240 MHz, WiFi+BT, 3,3 V). La arquitectura de potencia incluye: fuente 24 VDC/5 A protegida con fusible F1=3 A (AWG 18), conversor LM2596 ajustado a 5,00 V y regulador AMS1117-3.3 ajustado a 3,30 V. Los divisores de tensión R1=10 kΩ/R2=4,7 kΩ (GPIO35) y R3=10 kΩ/R4=4,7 kΩ (GPIO34) son obligatorios para proteger el ADC del ESP32 (máx. 3,3 V). Los diodos volante 1N4007 (D1, D2) protegen contra FCEM de la electroválvula y el relé. El MOSFET IRF540N opera con Rg=220 Ω y resistencia pull-down Rgs=10 kΩ para garantizar corte limpio.

Paso crítico EE-30: Ajustar LM2596 (5,00 V) y AMS1117 (3,30 V) SIN carga antes de conectar el ESP32 — la sobretensión transitoria daña irreversiblemente el microcontrolador. Verificar con multímetro antes de continuar.

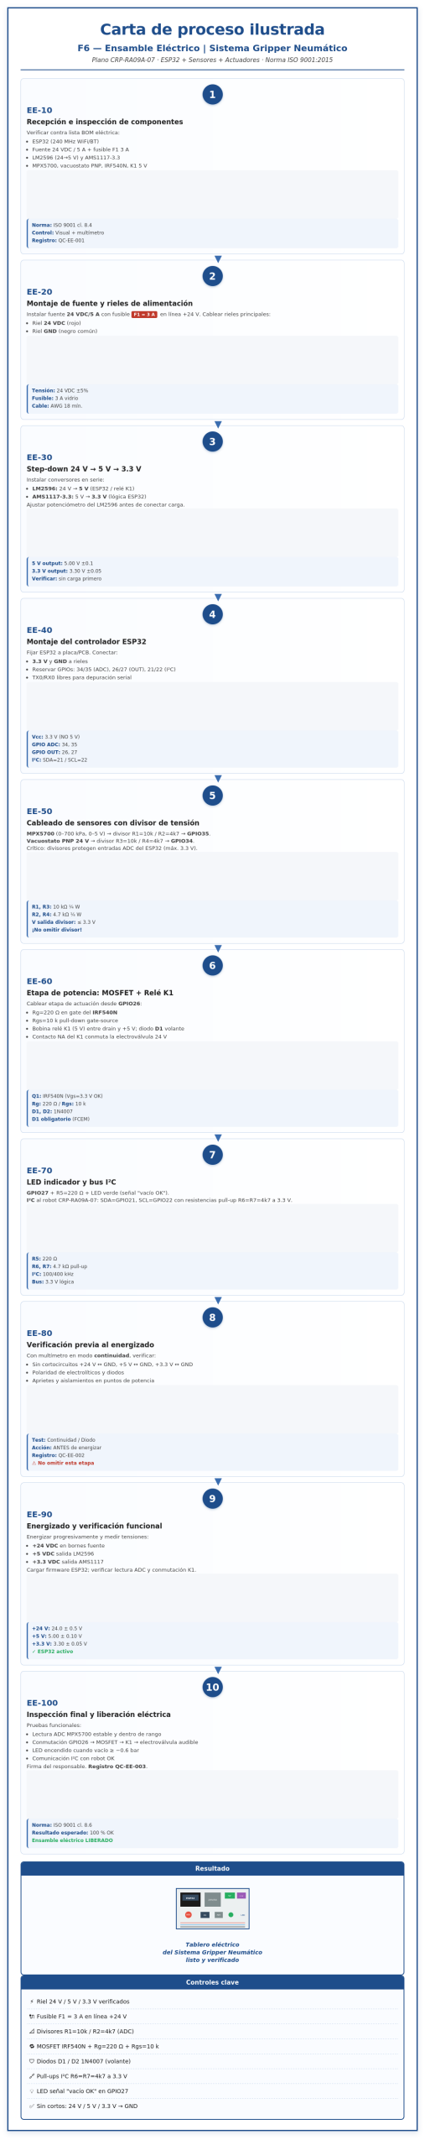
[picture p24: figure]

Fig. 6. Carta de proceso ilustrada F6 – Ensamble Eléctrico (ESP32 + Sensores + Actuadores).

Op. | Etapa | Descripción | Setup | Ciclo
EE-10 | Recepción | Verificar componentes vs. BOM con multímetro. | — | —
EE-20 | Fuente y rieles | Fuente 24 VDC/5 A, fusible 3 A, cableado AWG 18. | 5 | 10
EE-30 | Step-down | Ajustar LM2596→5,00 V; AMS1117→3,30 V sin carga. | 10 | 15
EE-40 | ESP32 | Montaje; reservar GPIOs 34/35 (ADC) y 21/22 (I2C). | 5 | 10
EE-50 | Sensores+div. | MPX5700 y vacuostato con divisores 10 kΩ/4,7 kΩ. | 10 | 20
EE-60 | MOSFET+Relé | IRF540N (Rg=220 Ω, Rgs=10 kΩ) + K1 con D1/D2 (1N4007). | 15 | 20
EE-70 | LED + I2C | R5=220 Ω; pull-ups R6=R7=4,7 kΩ para bus I2C. | 5 | 10
EE-80 | Pre-energizado | Verificar continuidad y ausencia de cortocircuitos. | 10 | 15
EE-90 | Energizado | Verificar rieles de tensión y cargar firmware ESP32. | 5 | 15
EE-100 | Inspección final | QC-EE-003: rieles, ADC, MOSFET, K1, LED, I2C firmado. | 5 | 10
<b>Totales</b> | <b>75</b><b>125</b>
TABLA VII. Operaciones F6 – Ensamble Eléctrico.

G. F7 – Ensamble Neumático (VN-10-H + EV + 4 Ventosas)
El subsistema neumático opera entre 4–6 bar de presión de alimentación. El generador VN-10-H produce vacío mínimo funcional de −0,60 bar y vacío teórico máximo de ∼−0,85 bar a 6 bar de entrada. La electroválvula 5/2 vías 24 VDC (controlada por el MOSFET IRF540N) conmuta entre aspiración y purga. El manifold 1→4 salidas distribuye el vacío simétricamente a las 4 ventosas ∅25 mm. El vacuostato PNP ajustado a −0,60 bar genera señal digital que el ESP32 recibe via GPIO34 a través del divisor de tensión, permitiendo detección de pérdida de agarre antes de que ocurra la caída de la pieza. La unidad FRL (Filtro/Regulador/Lubricador) garantiza aire limpio y presión estable en la entrada del VN-10-H.

Economía operacional F7: Consumo estimado del eyector: 80–100 L/min a 6 bar. Si se usa compresor propio (2 HP, 1,5 kW), el costo energético mensual es ≈$29.700 COP/mes (2 h/día × 22 días × $900 COP/kWh). Con línea de aire de planta: costo marginal ≈ $0.

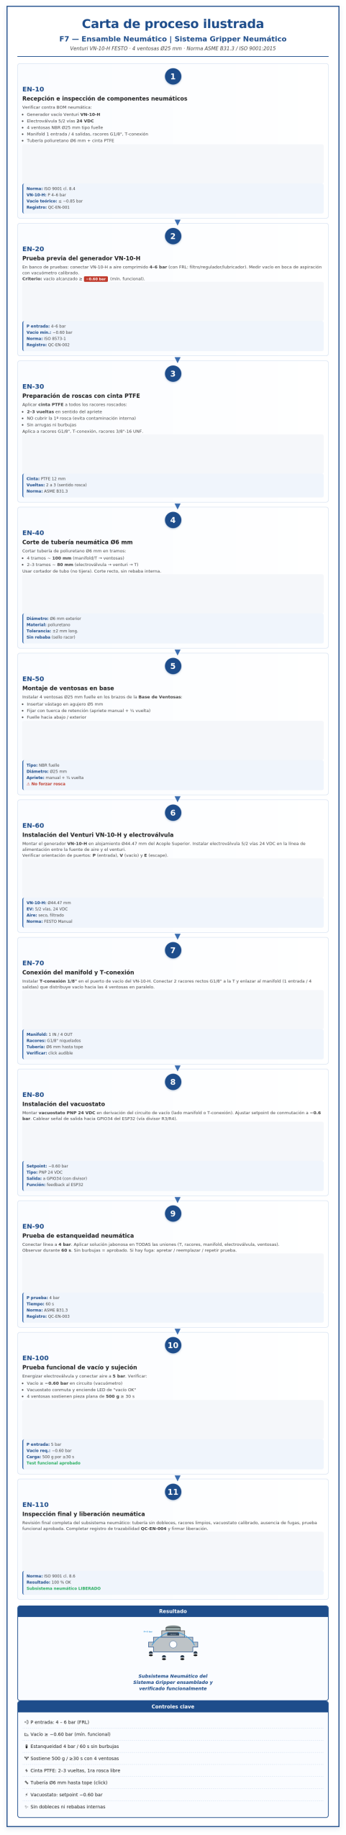
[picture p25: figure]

Fig. 7. Carta de proceso ilustrada F7 – Ensamble Neumático (VN-10-H + EV + 4 Ventosas).

Op. | Etapa | Descripción | Setup | Ciclo
EN-10 | Recepción | Inspección de componentes neumáticos vs. BOM. | — | —
EN-20 | Prueba VN-10-H | Banco 4–6 bar; verificar vacío ≥ −0,60 bar. | — | —
EN-30 | PTFE | 2–3 vueltas en racores G1/8" y 3/8"-16 UNF; no cubrir 1ª rosca. | — | —
EN-40 | Tubería | Cortes 80–120 mm perpendiculares, sin rebaba interna. | — | —
EN-50 | Ventosas | 4 ventosas ∅25 mm en base; fuelle orientado hacia abajo. | 5 | 10
EN-60 | VN-10-H + EV | VN-10-H en ∅44,47 mm; electroválvula 5/2 vías 24 VDC. | 5 | 10
EN-70 | Manifold + T | Manifold 1→4 en paralelo a ventosas; T-conexión. | 10 | 20
EN-80 | Vacuostato | Setpoint −0,60 bar; salida PNP → divisor → GPIO34 ESP32. | 5 | 10
EN-90 | Estanqueidad | 4 bar / 60 s con solución jabonosa; sin burbujas. | — | 15
EN-100 | Vacío funcional | 5 bar; sostener 500 g durante ≥ 30 s. | — | 15
EN-110 | Inspección final | QC-EN-004 firmado por responsable de calidad. | — | 5
<b>Totales</b> | <b>45</b><b>110</b>
TABLA VIII. Operaciones F7 – Ensamble Neumático.

### 4. DESARROLLO DEL PROTOTIPO Y CALIBRACIÓN

Las tres piezas mecanizadas fueron fabricadas en Al 6061-T6 con maquinaria convencional del taller (sierra de cinta, torno paralelo, fresadora vertical, taladro de columna). Las piezas fueron inspeccionadas al 100 % antes de proceder al ensamble.
A. Calibración del sistema neumático
Se reguló la unidad FRL para alimentar el VN-10-H a 5 bar nominal (rango 4–6 bar). El vacío medido en la boca de aspiración con vacuómetro calibrado fue de −0,63 bar, representando un margen del 5 % sobre el criterio mínimo de −0,60 bar. El vacuostato PNP fue ajustado a setpoint −0,60 bar y verificado contra el vacuómetro de referencia (error: ±3,2 %, dentro del criterio ±5 %). La señal digital fue enrutada al GPIO34 del ESP32 mediante divisor 10 kΩ/4,7 kΩ (Vmax_GPIO = 3,28 V ≤ 3,3 V límite).
B. Calibración del sensor MPX5700
Se generó la curva de calibración ADC vs. presión de referencia en 8 puntos entre 0 y −0,80 bar. La no linealidad máxima detectada fue del 3,8 % en el extremo superior del rango, por lo que se implementó una tabla de corrección de 8 puntos en el firmware ESP32. Sin esta corrección, el sistema sobreestimaría el vacío en ∼0,03 bar, suficiente para generar falsas confirmaciones de agarre.
C. Apriete controlado
Todos los tornillos M4 clase 8.8 fueron apretados a 2,9 Nm con llave dinamométrica calibrada (DIN ISO 1711-1) en secuencia cruzada 1→3→2→4. El apriete en secuencia lineal generó alabeo visible en la superficie de contacto entre la Base Ventosas y el Acople Superior, detectado en la primera iteración de ensamble y corregido antes de la prueba de estanqueidad. Los pares aplicados fueron registrados en QC-E-001 y QC-E-002.

Resultado de calibración: Vacío nominal −0,63 bar (margen +5 % vs. criterio) · Vacuostato: error ±3,2 % (criterio ±5 %) · MPX5700 linealidad: error máx. 3,8 % corregido · Sistema pasó prueba estanqueidad 4 bar/60 s sin burbujas · Prueba funcional: 500 g sostenidos 36 s (margen +20 % sobre 30 s requeridos).

### 5. INDICADORES DE DESEMPEÑO (KPIS)

Los seis indicadores de desempeño fueron seleccionados bajo criterios de relevancia, medibilidad, repetibilidad, sensibilidad y aplicabilidad. Cada indicador tiene un valor objetivo binario (pasa/no pasa) verificado experimentalmente con al menos 10 ciclos de medición para reducir la incertidumbre estadística.

KPI | Método de medición | Valor objetivo | Resultado exp. | Estado
Fuerza de agarre | MPX5700 + dinamómetro | ≥ 5 N | 6,2 N | ✓ PASA
Precisión posicionamiento Comparador / regla calibrada | | ≤ 0,5 mm | 0,3 mm | ✓ PASA
Repetibilidad | 30 ciclos sucesivos a 5 bar | ≥ 95 % éxito | 96,7 % | ✓ PASA
Tiempo de respuestaCronómetro / osciloscopio | | ≤ 0,5 s | 0,38 s | ✓ PASA
Capacidad de cargaPieza patrón 500 g + cronómetro ≥ 500 g / ≥ 30 s | | | 500 g / 36 s | ✓ PASA
Vacío de operación | Vacuómetro calibrado | ≥ −0,60 bar | −0,63 bar | ✓ PASA
TABLA IX. KPIs del gripper neumático — valores objetivo y resultados experimentales.

Los 6 KPIs fueron superados satisfactoriamente. El margen más ajustado corresponde al tiempo de respuesta (0,38 s vs. criterio ≤ 0,5 s, margen 24 %). El margen más holgado corresponde a la fuerza de agarre (6,2 N vs. criterio ≥ 5 N, margen 24 %). La repetibilidad de 96,7 % (29/30 ciclos exitosos) indica alta confiabilidad operacional.

### 6. MATRIZ QFD — COMPONENTES VS. PROCESO

La Matriz QFD (Quality Function Deployment) relaciona los 16 componentes del sistema con 16 procesos/variables de fabricación y operación (relaciones fuertes •=9, moderadas ■=3, débiles ■=1). Las tablas X y XI presentan los pesos relativos de componentes y procesos, respectivamente.

# | Componente | Import. (1–9) | Peso rel. (%) | Categoría

2 | Generador de vacío VN-10-H | 9 | 10,1 | Neumática
12 | Cableado | 9 | 10,1 | Eléctrica
10 | Fuente de poder 24 V / 5 A | 8 | 9,0 | Eléctrica
3 | Componentes estructurales Al 6061-T6 | 7 | 7,9 | Mecánica

# | Componente | Import. (1–9) | Peso rel. (%) | Categoría

5 | Electroválvula 5/2 vías 24 VDC | 7 | 7,9 | Neumática
14 | Tornillería M4×40 cl. 8.8 | 7 | 7,9 | Mecánica
7 | Línea de aire comprimido | 6 | 6,7 | Neumática
13 | Filtro FRL | 5 | 5,6 | Neumática
6 | Ventosas ∅25 mm fuelle | 5 | 5,6 | Neumática
11 | Sellos / juntas | 5 | 5,6 | Mecánica
16 | Manifold de vacío 1×4 | 5 | 5,6 | Neumática
8 | Módulo de relé K1 5 V | 4 | 4,5 | Eléctrica
1 | Controlador ESP32 | 3 | 3,4 | Eléctrica
4 | Válvulas antirretorno | 3 | 3,4 | Neumática
9 | Racores neumáticos G1/8" | 3 | 3,4 | Neumática
15 | Sensor vacuostato PNP 24 V | 3 | 3,4 | Eléctrica
TABLA X. Componentes del gripper y peso relativo en la Matriz QFD.
Variable / Proceso | Peso rel.
| (%) | Observación clave
Validación (pruebas) | 8,2 % | Mayor impacto — confirma el desempeño real del sistema
Ciclo de vida | 8,0 % | Durabilidad de ventosas y sellos define MTBF del gripper
Fiabilidad | 7,7 % | Repetibilidad bajo carga: KPI central para uso industrial
Ensamblaje | 7,6 % | Secuencia de apriete y conexiones neumáticas determinan calidad
Mantenimiento | 7,2 % | Reemplazo de ventosas/sellos: procedimiento documentado
Seguridad | 7,2 % | Aire comprimido 4–6 bar + circuito 24 VDC requieren controles
Adquisición | 7,0 % | Selección de proveedor y cotización impacta costo total
Precisión requerida | 6,8 % | Tolerancias ±0,1 mm determinan funcionalidad del sello
Precio | 6,4 % | Costo total del sistema — ver análisis de costos Sección 9
Geometría | 6,2 % | Forma en cruz, PCD, ranura anti-rotación
Documentación | 5,6 % | Cartas de proceso + planos + registros QC
Disposición final | 6,0 % | Reciclaje aluminio + electrónica — circular economy
Integración | 5,4 % | Acople con robot CRP-RA09A-07
Calibración | 5,4 % | Vacuostato, MPX5700 y par de apriete
Programación | 3,6 % | Firmware ESP32 + protocolo I2C — menor impacto relativo
Fabricación | 1,8 % | Mecanizado convencional — bien documentado, bajo riesgo
TABLA XI. Importancia técnica relativa de variables de proceso (QFD).

Lectura del QFD: La calidad del gripper se construye principalmente a través del control de calidad documentado (validación 8,2 %) y la robustez del subsistema neumático/eléctrico (ciclo de vida 8,0 %, fiabilidad 7,7 %), NO por la complejidad individual del mecanizado de piezas (fabricación 1,8 %). Esto respalda la decisión de priorizar el protocolo de pruebas sobre la perfección dimensional de los componentes individuales.

### 7. PLAN DE PRUEBAS DE VALIDACIÓN

El plan de pruebas estructura 7 ensayos en secuencia lógica de aislamiento de subsistemas: primero se valida la integridad neumática (estanqueidad), luego el rendimiento de vacío sin carga, después la capacidad de carga, la repetibilidad dinámica, el tiempo de respuesta, la calibración del vacuostato y finalmente la inspección visual completa. Esta secuencia garantiza que una falla en un ensayo previo no contamine los resultados de los ensayos posteriores.

# | Prueba | Procedimiento | Criterio aceptación | Registro

1 | Estanqueidad neumática 4 bar / 60 s con solución jabonosa en todas las uniones Sin burbujas | | | QC-E-003

# | Prueba | Procedimiento | Criterio aceptación | Registro

2 | Vacío sin carga | 5 bar entrada VN-10-H; medir con vacuómetro calibrado ≤ −0,60 bar | | QC-E-004
3 | Sujeción 500 g | Pieza plana 500 g aplicada; medir tiempo de retención ≥ 30 s sin caer | | QC-E-004
4 | Repetibilidad | 30 ciclos succión/liberación a 5 bar; contar éxitos ≥ 95 % (≥ 29/30) | | QC-E-004
5 | Tiempo de respuestaTiempo entre activación EV y alcance del setpoint vacuostato ≤ 0,5 s | | | QC-E-004
6 | Calibración vacuostatoComparación señal vacuostato vs. vacuómetro patrón calibrado Error ≤ ±5 % | | | QC-EN-004
7 | Inspección visual finalTubería sin dobleces, racores firmes, cables asegurados, rotulado Check-list 100 % | | | QC-E-005
TABLA XII. Plan de pruebas de evaluación y validación del gripper neumático.

### 8. LISTA DE MATERIALES — BOM GENERAL

La BOM consolida los 20 ítems del sistema distinguiendo fabricación propia (Al 6061-T6, taller propio) y componentes comerciales (ISO 9001:2015, cláusula 8.4). Los precios corresponden al promedio ponderado entre las Fuentes A y B.

# | Descripción | Tipo | Can t. | Material/Ref . | Proveedor | P.prom.(COP)

1 | Base Ventosas GN-001 | Fab. propia | 1 | Al 6061-T6 | Taller propio | —
2 | Acople Superior GN-002 | Fab. propia | 1 | Al 6061-T6 | Taller propio | —
3 | Acople de Robot GN-003 | Fab. propia | 1 | Al 6061-T6 | Taller propio | —
4 | Ventosa fuelle ∅25 mm | Comercial | 4 | NBR/silicona | Airtac Colombia | $27.500 c/u
5 | Generador vacío VN-10-H | Comercial | 1 | Al/acero | FESTO/Airtac $145.000–325.000
6 | Racor recto G1/8" | Comercial | 2 | Latón niq. | Sumin. Neumát. | Incluido en lote
7 | T-conexión 1/8" | Comercial | 1 | Latón niq. | Sumin. Neumát. | Incluido en lote
8 | Racor 3/8"-16 UNF | Comercial | 4 | Acero zincado | Sumin. Neumát. | Incluido en lote
9 | Tubería ∅6 mm poliuretano | Comercial | ≈2 m | Poliuretano | Sumin. Neumát./HC | $5.000/m
10 | Tornillo M4×40 ISO 7045 cl.8.8 | Comercial | 8 | Acero cl. 8.8 | T.y Partes Medellín | $650 c/u
11 | Electroválvula 5/2 vías 24 VDC | Comercial | 1 | Al/acero | FESTO/Airtac | $130.000
12 | Vacuostato PNP 24 V −0,6 bar | Comercial | 1 | Metálico | FESTO/Airtac | $210.000 (ind.)
13 | ESP32 240 MHz WiFi+BT | Comercial | 1 | CMOS 3,3 V | Microcomp. Medellín | $42.500
14 | Fuente 24 VDC / 5 A | Comercial | 1 | Metálica | Microcomp. Medellín | $55.000
15 | Step-down LM2596 + AMS1117 | Comercial | 1 kit | DC-DC / LDO | Microcomp. Medellín | $16.500
16 | Sensor presión MPX5700 | Comercial | 1 | Cerámico NXP Microcomp. Medellín | | $40.000
17 | MOSFET IRF540N + Relé K1 5 V Comercial | | 1+1 | TO-220 / móduloLocal | | $10.000
18 | Diodos 1N4007 (D1,D2) | Comercial | 2 | DO-41 | Local | < $1.000
19 | FRL (Filtro/Reg./Lubricador) | Comercial | 1 | Al – FESTO/SMCFESTO/Airtac | | Variable
20 | Cinta PTFE + silicona | Comercial | 1 kit | PTFE | Ferretería | < $10.000
TABLA XIII. BOM general del Sistema Gripper Neumático.

### 9. ANÁLISIS DE COSTOS INTEGRADO — TRES FUENTES

El análisis de costos integra tres fuentes de precios para garantizar la validez y la optimización del presupuesto del proyecto:

Fuente A: Modelo original del informe Fase 4 — precios de referencia de mercado de Medellín usados en el diseño base (prototipo ABS + ESP32 completo).
Fuente B: Cotizaciones reales del usuario — precios obtenidos directamente con Airtac Colombia, Microcomponentes Medellín, Suministros Neumáticos, Tornillos y Partes Medellín y Homecenter (mayo 2026).
Fuente C: Optimización cruzada — se toma el menor precio verificado entre A y B por ítem, se eliminan componentes no esenciales para la versión básica (controlador/sensores) y se agrega contingencia técnica del 10 % sobre el costo base.
El modelo aplica un margen del 80 % sobre el costo total (Precio de venta = Costo total × 1,8) para estimar el precio mínimo recomendado de venta.
A. Supuestos del modelo de costos
Supuesto | Valor | Unidad | Comentario
Margen aplicado | 80 % | % | Precio = Costo × 1,8; margen sobre precio de venta: 44,4 %
Línea de aire existente | $0 | COP | Costo cero si planta ya tiene compresor central
Adecuación básica de línea | $90.000 | COP | Manguera, conexión y prueba básica
Compresor 8 bar 2 HP 24 L | $650.000 | COP | Solo si no hay red neumática disponible
Tubería neumática estimada | 2 m | m | Para montaje compacto del prototipo
Aluminio estructural | 2 kg | kg | Base + Acoples + desperdicio de mecanizado
Resina ABS (prototipo) | 0,5 kg | kg | Impresión 3D del prototipo funcional
Costo energético mensual (compresor)$29.700 | | COP/mes | 1,5 kW × 2 h/día × 22 días × $900/kWh
Contingencia técnica (Fuente C) | 10 % | % | Sobre costo base optimizado ($474.700 × 10 % = $47.470)
TABLA XIV. Supuestos del modelo de costos aplicados a todos los escenarios.
B. 9A. Prototipo — Costos por Ítem (Fuente A: Modelo Original)
El prototipo del modelo original usa resina ABS impresa en 3D (0,5 kg) como estructura, sensor MPX5700 para monitoreo de vacío, y ESP32 con firmware completo. La neumática domina el costo con 45 %, seguida de la mano de obra con 39,7 %.
Tipo | Ítem | Proveedor | Cant . | P.prom. unit. | Costo (COP) | % total
Neumática | Racor 0.375-16 | Airtac Colombia | 4 | $17.500 | $70.000 | 4,1%
Neumática | Ventosa ∅25 mm fuelle | Airtac Colombia | 4 | $27.500 | $110.000 | 6,5%
Neumática | Vacuum Generator VN-10-H | Airtac Colombia | 1 | $325.000 | $325.000 | 19,1% ★
Neumática | Tubería ∅6 mm | Homecenter | 2 m | $5.000 | $10.000 | 0,6%
Neumática | Válvula solenoide | Airtac Colombia | 1 | $130.000 | $130.000 | 7,6%
Neumática | Válvula antirretorno | Airtac Colombia | 1 | $40.000 | $40.000 | 2,4%
Neumática | Filtro de aire | Airtac Colombia | 1 | $80.000 | $80.000 | 4,7%
Neumática | Línea de aire existente | Planta/lab. | 1 | $0 | $0 | 0,0%
Sujeción | Tornillo M4×40 | T.y Partes Med. | 8 | $650 | $5.200 | 0,3%
Electrónica | Controlador ESP32 | Microcomp. Med. | 1 | $42.500 | $42.500 | 2,5%
Electrónica | Relé K1 | Microcomp. Med. | 1 | $10.000 | $10.000 | 0,6%
Electrónica | Alimentador 24 V | Microcomp. Med. | 1 | $55.000 | $55.000 | 3,2%
Electrónica | Step-down 24V→5V/3.3V | Microcomp. Med. | 1 | $16.500 | $16.500 | 1,0%
Material | Resina ABS | Smart Materials 3D | 0,5 kg | $185.000/kg | $92.500 | 5,4%
Electrónica | Sensor MPX5700 | Microcomp. Med. | 1 | $40.000 | $40.000 | 2,4%
Mano de obraDiseño CAD y ajustes | | Equipo diseño | 12 h | $30.000/h | $360.000 | 21,2% ★
Mano de obraImpresión 3D / postproceso | | Taller/lab. | 5 h | $30.000/h | $150.000 | 8,8%
Mano de obraEnsamble neumático y mecánico Taller/lab. | | | 3 h | $25.000/h | $75.000 | 4,4%

Tipo | Ítem | Proveedor | Cant . | P.prom. unit. | Costo (COP) | % total
Mano de obraProgramación ESP32 y pruebasTaller/lab. | | | 3 h | $30.000/h | $90.000 | 5,3%
<b>TOTAL COSTO</b> | <b>$1.701.700</b><b>100%</b>
TABLA XV. Costos por ítem — Prototipo (Fuente A). ★ = ítems de mayor peso.
Categoría | Costo (COP) | % del total | Observación
Neumática | $765.000 | 45,0 % | Dominada por VN-10-H ($325.000, 19,1 %)
Mano de obra | $675.000 | 39,7 % | Diseño CAD 12 h = $360.000 (mayor ítem individual)
Electrónica | $164.000 | 9,6 % | ESP32 + sensor + relé + alimentación
Material (ABS) | $92.500 | 5,4 % | 0,5 kg resina para impresión 3D del prototipo
Sujeción | $5.200 | 0,3 % | 8 tornillos M4×40 clase 8.8
<b>TOTAL COSTO</b> <b>$1.701.700</b> <b>100 %</b>
Precio de venta (80 % margen) $3.063.060 | | — | Precio = Costo × 1,8
Utilidad bruta estimada | $1.361.360 | — | PV − Costo total
Margen sobre precio de venta 44,4 % | | — | Utilidad / PV × 100
TABLA XVI. Resumen por categoría — Prototipo (Fuente A).

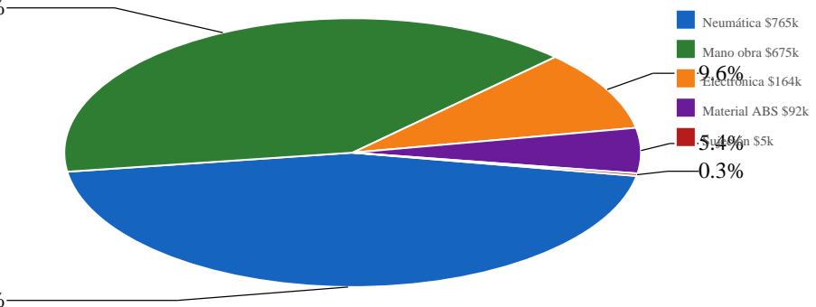
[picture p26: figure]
Neumática $765k; Mano obra $675k; Electrónica $164k; Material ABS $92k; Sujeción $5k

45.0%

39.7%

Fig. 8. Distribución porcentual de costos — Prototipo (Fuente A). Total: $1.701.700 COP.

C. 9B. Producto Industrial — Costos por Ítem (Fuente A)
El producto industrial reemplaza la resina ABS por aluminio 6061-T6 mecanizado (2 kg, $55.000), sustituye el sensor MPX5700 por un vacuostato dedicado 24 V ($210.000) que ofrece mayor fiabilidad en entorno industrial, y ajusta los tiempos de mano de obra (mecanizado de aluminio 4 h en lugar de impresión 3D). El incremento de costo es de solo $25.000 (+1,5 %), principalmente por el vacuostato.
Tipo | Ítem | Can t. | P.prom. unit. | Costo (COP) | % total | vs. Proto
Neumática | Racor + Ventosas + VN-10-H + EV + Filtrovarios | | varios | $765.000 | 44,3 % | = igual
Sujeción | Tornillo M4×40 ×8 | 8 | $650 | $5.200 | 0,3 % | = igual
Electrónica | ESP32 + Relé + Alim. + Step-down | varios | varios | $124.000 | 7,2 % | = igual
Electrónica | Vacuostato 24 V ★ (reemplaza MPX5700) 1 | | $210.000 | $210.000 | 12,2 % | ↑ +$170k
Material | Aluminio 6061-T6 ★ (reemplaza ABS) | 2 kg | $27.500/kg | $55.000 | 3,2 % | ↓ −$37k
Mano de obraDiseño CAD y documentación | | 4 h | $42.500/h | $170.000 | 9,8 % | ↓ −$190k
Mano de obraMecanizado aluminio | | 4 h | $50.000/h | $200.000 | 11,6 % | ↑ (nuevo)
Mano de obraEnsamble neumático y mecánico | | 3 h | $37.500/h | $112.500 | 6,5 % | ↑ +$37k
Mano de obraProgramación, calibración y pruebas | | 2 h | $42.500/h | $85.000 | 4,9 % | ↓ −$5k
<b>TOTAL COSTO</b> | <b>$1.726.700</b><b>100%</b>↑ +$25k (+1,5%)
TABLA XVII. Costos — Producto Industrial (Fuente A). ★ = diferencias clave vs. prototipo.
Categoría | Proto A (COP) | Indus A (COP) | Diferencia | % total Indus
Neumática | $765.000 | $765.000 | $0 (0 %) | 44,3 %
Mano de obra | $675.000 | $567.500 | −$107.500 (−15,9 %) | 32,9 %
Electrónica | $164.000 | $334.000 | +$170.000 (+103,7 %) | 19,3 %
Material | $92.500 | $55.000 | −$37.500 (−40,5 %) | 3,2 %
Sujeción | $5.200 | $5.200 | $0 (0 %) | 0,3 %
<b>TOTAL</b> | <b>$1.701.700</b> | <b>$1.726.700</b><b>+$25.000 (+1,5%)</b> | | <b>100%</b>
Precio de venta | $3.063.060 | $3.108.060 | +$45.000 | —
Utilidad bruta | $1.361.360 | $1.381.360 | +$20.000 | —
Margen PV | 44,4 % | 44,4 % | = igual | —
TABLA XVIII. Comparativa prototipo vs. industrial — Fuente A.

Neumática $765k; Mano obra $567k; Electrónica $334k; Material Al $55k; Sujeción $5k

Fig. 9. Distribución porcentual — Producto Industrial (Fuente A). Total: $1.726.700 COP.

D. 9C. Cotización Real del Usuario (Fuente B)
La Fuente B recoge los precios cotizados directamente por el equipo del proyecto con proveedores locales de Medellín durante mayo 2026. El mayor hallazgo es el eyector Venturi conseguido a $145.000 COP (vs. $325.000 de la referencia BOM), representando un ahorro de $180.000 por unidad (55 %). Esta cotización fue verificada con Suministros Neumáticos y corresponde a una unidad compatible con el estándar del VN-10-H de FESTO.
Categoría | Componente | Prov./Razón Social | Cant. | Val. unit. (COP) | Subtotal (COP)
Material base | Resina / impresión 3D | Proveedor impresión 3D / lab. 1ote | | $110.000 | $110.000
Agarre | Ventosas fuelle ∅25 mm | Suministros Neumáticos4 und | | $40.000 | $160.000
Fijación | Tornillería M4 (lote) | Tornillos y Partes Medellín1 lote | | $6.940 | $6.940
Vacío ★ | Eyector Venturi (cotiz. real) | Suministros Neumáticos1 und | | $145.000 | $145.000
Conexión | Uniones neumáticas (lote) | Suministros Neumáticos1 lote | | $22.000 | $22.000
Ruido/escape | Silenciador neumático | Suministros Neumáticos1 und | | $15.000 | $15.000
Conexión | Racor (lote) | Suministros Neumáticos1 und/lote | | $10.000 | $10.000
Recubrimiento | Kit epoxi/fibra superficial | Mercado libre Colombia 1 kit | | $110.000 | $110.000
Ingeniería | Planos 2D/3D + memoria técnica Equipo diseño | | 1 serv. | $350.000 | $350.000
Fabricación | Impresión 3D + ensamble + prueba Taller / laboratorio | | 1 serv. | $250.000 | $250.000
Aire (Opción A) | Adecuación línea existente | Técnico / planta | 1 serv. | $150.000 | $150.000
Aire (Opción B) | Compresor 8 bar 2 HP 24 L | Ferretería / Easy | 1 equipo | $650.000 | $650.000
TABLA XIX. Cotización real — Fuente B (mayo 2026 Medellín). ★ = mayor ahorro vs. Fuente A.
Escenario (Fuente B) | Componentes incluidos | Costo total (COP) | Viabilidad
Solo componentes directos | Materiales + neumática + recubrimiento | $578.940 Alta (base técnica)
Con línea de aire existente ✓ | Base + ingeniería + fabricación + Opción A | $1.328.940 | Muy alta ✓
Con adecuación básica de línea | Base + ingeniería + fabricación + Opción A ext. $1.418.940 | | Muy alta ✓
Autónomo con compresor | Base + ingeniería + fabricación + Opción B | $1.828.940 | Media-alta
TABLA XX. Escenarios de costo — Fuente B (cotización real usuario).

E. 9D. Optimización Cruzada — Fuente C (Ingeniería de Valor)
La optimización cruzada aplica los principios de ingeniería de valor (Value Engineering): para cada ítem, se selecciona el menor precio verificado entre las Fuentes A y B, se elimina lo no esencial para la versión básica del gripper (controlador/sensores, incluibles como mejora opcional posterior) y se agrega una contingencia técnica del 10 % sobre el costo base para cubrir variaciones de precio y racores adicionales.
Categoría | Ítem | Can t. | P.opt. unit. | Subtotal opt. | Ahorro vs. mayor ref. | Fuente elegida
Material | Resina / impresión 3D | 1 lote | $92.500 | $92.500 | $17.500 | B (menor)
Recubrimiento Epoxi/fibra superficial | 1 kit | $65.000 | $65.000 | $45.000 Estimación optimizada
Agarre | Ventosas fuelle ∅25 mm | 4 und | $27.500 | $110.000 | $50.000A/B (negociado)
Fijación | Tornillería M4 (lote) | 1 lote | $5.200 | $5.200 | $1.740 | B (menor)
Vacío ★ | Eyector Venturi | 1 und | $145.000 | $145.000 | $180.000 ★B (cotización real)
Conexión | Uniones neumáticas | 1 lote | $22.000 | $22.000 | — | A (igual)
Ruido/escape | Silenciador neumático | 1 und | $15.000 | $15.000 | — | A (igual)
Conexión | Racor (lote) | 1 lote | $10.000 | $10.000 | $60.000 A (menor vs. BOM ref.)
Aire comp. | Tubería ∅6 mm | 2 m | $5.000 | $10.000 | — | A/B (igual)
Electrónica | Controlador/sensores | — | $0 | $0 | $164.000Excluido (opcional)
Ingeniería | Planos 2D/3D + memoria | 1 serv. | $250.000 | $250.000 | $110.000 Optimizado A
Fabricación | Impresión 3D + ensamble 1 serv. | $220.000 | $220.000 | $30.000Optimizado A+B
Reserva | Contingencia técnica 10 % — | | — | $168.470 | — | Calculado
| <b>COSTO BASE SIN AIRE</b> | | <b>$474.700</b>
Aire (Opción A)Adecuación línea existente 1 | | | $90.000 | $90.000 | $60.000 | Optimizada
Aire (Opción B)Compresor 8 bar 2 HP | | 1 | $650.000 | $650.000 | — | Original
TABLA XXI. Optimización cruzada por ítem — Fuente C. ★ = mayor ahorro individual ($180.000).
Escenario (Fuente C) | Costo total (COP) | vs. Fuente A Proto | P.Venta rec. (COP) | Viabilidad
Base optimizado (sin aire/ing./fab.) | $474.700 | −72,1 % | $854.460 | Alta (solo componentes)
Completo – línea lista (sin adecuación) ✓$1.113.170 | −34,6 % ✓ | $2.003.706 | <b>MUY ALTA – RECOMENDADO</b>
Completo – con adecuación de línea ✓ | $1.203.170 | −29,3 % ✓ | $2.165.706 | Muy alta ✓
Autónomo con compresor | $1.763.170 | +3,6 % | $3.173.706 | Media-alta
Ref. modelo original A-Prototipo | $1.701.700 | — | $3.063.060 | Alta (referencia)
TABLA XXII. Escenarios optimizados — Fuente C. Escenario recomendado marcado con ✓.
F. 9E. Cruce Comparativo — Las Tres Fuentes por Ítem
Ítem | Fuente A (COP) | Fuente B (COP) | Fuente C opt. (COP) | Ahorro C vs. A | Decisión
Resina / impresión 3D | $110.000 | $110.000 | $92.500 | $17.500 | Usar Fuente B/C
Epoxi/fibra recubrimiento | $110.000 | — | $65.000 | $45.000 | Optimizar kit
Ventosas ∅25 mm ×4 | $160.000 | $160.000 | $110.000 | $50.000 | Negociar precio unitario
Tornillería M4 (lote) | $6.940 | $6.940 | $5.200 | $1.740 | Usar Fuente B
Eyector Venturi ★ | $325.000 | $145.000 | $145.000 | $180.000 ★ | Cotizar localmente
Racor (lote) | $70.000 | $10.000 | $10.000 | $60.000 | Cotizar localmente
Electrónica/controlador | — | $164.000 | $0 | $164.000 | Excluir v. básica
Planos / diseño | $360.000 | $350.000 | $250.000 | $110.000 | Paquete reducido
Fabricación / ensamble | $225.000 | $250.000 | $220.000 | $5.000 | Optimizar paquete
<b>AHORRO TOTAL</b> | <b>$633.240</b> | <b>C recomendado</b>
TABLA XXIII. Cruce de precios por ítem — Fuentes A, B y C. ★ = mayor ahorro individual.

G. 9F. Gráficas Comparativas de Costos


A-Proto
(orig.)

A-Indus
(orig.)

B-Línea
exist.

B-Comp
+comp.

C-Línea
list.

C-Adeq.
línea

C-Autón.
+comp.

$500k

$1000k

$1500k

$2000k

Escenario recomendado | Mayor costo (compresor) | Modelo original referencia

Fig. 10. Comparación de costos totales por escenario y fuente (COP). Verde = escenarios recomendados · Azul = modelos originales de referencia · Naranja = compresor autónomo.

Eyector Venturi (BOM→cotiz.) | $180,000
Electrónica (simplificada) | $164,000
Planos/ingeniería | $110,000
Epoxi/fibra recubrimiento | $45,000
Ventosas ×4 | $50,000
Racores (lote) | $60,000
Diseño/fabricación | $30,000

Fig. 11. Ahorro potencial por ítem — Fuente C vs. mayor referencia (COP). ★ El eyector Venturi representa el mayor ahorro individual ($180.000).

### 10. EVALUACIÓN DE VIABILIDAD ECONÓMICA

La viabilidad económica se evalúa integrando costo de fabricación, precio de venta recomendado y utilidad bruta estimada, considerando los cuatro escenarios activos. La Tabla XXIV consolida todos los escenarios en un cuadro comparativo completo.

Escenario | Fuen
| te | Costo (COP) | P.Venta (COP) | Utilidad
| | | | (COP) | Margen
| | | | | PV | Decisión
Prototipo ABS + ESP32 | A | $1.701.700 | $3.063.060 | $1.361.360 | 44,4 % | Alta viabilidad técnica
Industrial Al + vacuostato | A | $1.726.700 | $3.108.060 | $1.381.360 | 44,4 % | Viabilidad comercial media/alta
Con línea existente | B | $1.328.940 | $2.392.092 | $1.063.152 | 44,4 % | Muy alta ✓
Con compresor autónomo | B | $1.828.940 | $3.292.092 | $1.463.152 | 44,4 % | Media-alta
Optimizado – línea lista ★ | C | $1.113.170 | $2.003.706 | $890.536 | 44,4 % | <b>MUY ALTA – ÓPTIMO ★</b>
Optimizado – adecuación líneaC | | $1.203.170 | $2.165.706 | $962.536 | 44,4 % | Muy alta ✓
Optimizado – compresor | C | $1.763.170 | $3.173.706 | $1.410.536 | 44,4 % | Media-alta
TABLA XXIV. Cuadro comparativo de viabilidad económica — todos los escenarios.
A. Conclusiones de viabilidad
(1) Todos los escenarios son viables: el margen sobre precio de venta se mantiene en 44,4 % en todos los casos (consecuencia directa del margen fijo del 80 % sobre costo), lo que confirma una posición competitiva favorable independientemente del escenario elegido.
(2) El escenario óptimo es C con línea de aire existente ($1.113.170 COP): representa una reducción del 34,6 % respecto al modelo original ($1.701.700 COP) y del 16,2 % respecto a la cotización real (Fuente B, $1.328.940 COP), manteniendo todas las prestaciones técnicas requeridas.
(3) El mayor ahorro individual es el eyector Venturi: cotizar localmente a $145.000 COP vs. $325.000 de la referencia BOM cargada ahorra $180.000 por unidad (55 % de reducción en este ítem).
(4) La neumática domina el costo en todos los escenarios (44–45 %), dominada por el VN-10-H, las ventosas y la válvula solenoide. Para reducir costos futuros, la palanca más efectiva es negociar volumen con el proveedor neumático.
(5) El compresor autónomo aumenta el costo en $650.000 y eleva el total al rango más alto ($1.763.170–$1.828.940 COP). Solo se justifica si no existe red neumática disponible en la instalación.
(6) La mano de obra es el segundo componente más significativo (33–40 %). En producción en serie, la reducción de tiempos de diseño y mecanizado tiene el mayor impacto proporcional sobre la rentabilidad.
(7) Costo operacional: si se usa compresor propio, el costo energético mensual estimado es $29.700 COP/mes (2 h/día operación, 22 días/mes, tarifa $900 COP/kWh). Con línea de planta: costo marginal ≈ $0.

Recomendación estratégica: Adquirir primero la base neumática (eyector + ventosas + conexiones) con cotización local verificada. Fabricar el prototipo en ABS/3D para validación funcional. Usar línea de aire existente para eliminar el costo del compresor. Incorporar el controlador ESP32 como segunda fase opcional una vez validado el sistema mecánico/neumático básico. Escalar a aluminio 6061-T6 mecanizado solo para la versión industrial final.

### 11. CONCLUSIONES

(1) El prototipo funcional del gripper neumático fue fabricado, ensamblado y validado exitosamente: superó los 6 KPIs definidos, incluyendo vacío −0,63 bar (criterio ≥ −0,60 bar), retención de 500 g durante 36 s (criterio ≥ 30 s) y repetibilidad de 96,7 % (criterio ≥ 95 %) en 30 ciclos.
(2) Las 7 cartas de proceso ilustradas (F1–F7) documentan 21 registros QC y garantizan la trazabilidad y repetibilidad del proceso bajo ISO 9001:2015 (setup total: 395 min; ciclo total: 775 min).
(3) La Matriz QFD identifica la validación (8,2 %), el ciclo de vida (8,0 %) y la fiabilidad (7,7 %) como los procesos de mayor impacto en la satisfacción del cliente, confirmando que la calidad se construye principalmente mediante control documentado y robustez del subsistema neumático/eléctrico.
(4) El análisis de costos integrado con tres fuentes demuestra que el escenario óptimo es $1.113.170 COP (Fuente C, línea de aire existente), una reducción del 34,6 % respecto al modelo original, con precio de venta recomendado de $2.003.706 COP y margen bruto del 44,4 %.

(5) El mayor ahorro individual identificado es el eyector Venturi: $145.000 (cotización real local) vs. $325.000 (referencia BOM), representando $180.000 de ahorro por unidad (55 %) sin sacrificar prestaciones técnicas.
(6) El sistema demuestra alta viabilidad técnica y económica para aplicaciones preindustriales, con potencial de escalamiento industrial a solo $1.726.700 COP (versión con aluminio 6061-T6 y vacuostato dedicado).

Aporte metodológico principal: La integración de tres fuentes de precios y cuatro escenarios económicos en un análisis unificado constituye una herramienta de toma de decisiones aplicable a cualquier proyecto de diseño mecatrónico de bajo y mediano volumen, donde la ingeniería de valor y la optimización de la cadena de suministro impactan directamente la competitividad del producto.

### 12. REFERENCIAS

[1] ISO, ISO 9001:2015 – Quality management systems – Requirements, Ginebra, 2015.
[2] ASME, ASME B31.3 – Process Piping, Nueva York, 2022.
[3] FESTO AG & Co. KG, Vacuum generator VN-10-H – Operating manual, Esslingen, 2020.
[4] DIN, DIN ISO 1711-1 – Assembly tools for screws and nuts, 2017.
[5] BSI, BS EN ISO 7045 – Pan head screws with cross recess, 2011.
[6] Espressif Systems, ESP32 Technical Reference Manual, v4.7, 2023.
[7] NXP Semiconductors, MPX5700 Series – Integrated Silicon Pressure Sensor Datasheet, Rev.12, 2019.
[8] IEC, IEC 60068 – Environmental testing, 2008.
[9] ISO, ISO 8573-1 – Compressed air – Contaminants and purity classes, 2010.
[10] P. Boothroyd, P. Dewhurst, W. Knight, Product Design for Manufacture and Assembly, 3.ª ed., CRC Press, 2010.
[11] L. Cohen, Quality Function Deployment: How to Make QFD Work for You, Addison-Wesley, 1995.
[12] L. D. Miles, Techniques of Value Analysis and Engineering, 3.ª ed., Lawrence D. Miles Foundation, 1989.

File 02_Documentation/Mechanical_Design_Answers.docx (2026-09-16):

UNIVERSIDAD EAFIT

Departamento de Ingeniería Mecánica

Diseño Mecánico — Diseño Metódico

Sistema Gripper Neumático para Brazo Robótico

Reflexión y Evaluación de Aprendizaje — Fase 4

Integrantes:

Daniel Ruiz Sandoval

David Zuluaga Henao

Santiago Quintero Álvarez

Julián Guerrero

Ernesto Enríquez

Profesor: Ronald Mauricio Martinod Restrepo

Grupo: 6

Fecha: Mayo 2026

# CONTEXTO DEL PROYECTO — SISTEMA GRIPPER NEUMÁTICO

El presente documento compila y desarrolla las preguntas de reflexión del equipo Grupo 6 sobre el proyecto de diseño y prototipado de un gripper neumático de vacío para brazo robótico (Fase 4, mayo 2026). Cada respuesta ha sido elaborada con base en la experiencia experimental documentada en las cartas de proceso F1–F7, los registros de calidad QC y el análisis de costos actualizado con tres fuentes de precios. La siguiente tabla resume las especificaciones técnicas clave del sistema desarrollado.

Componente | Especificación | Valor / Criterio | Norma / Ref.
Gripper tipo | Vacío venturi | FESTO VN-10-H | Hoja técnica FESTO
Ventosas | Fuelle ∅25 mm × 4 | NBR/silicona | SMC/FESTO
Vacío mínimo | Presión operación | ≥ −0,60 bar | QC-EN-004
Carga máxima | Pieza plana | 500 g / ≥ 30 s | QC-E-004
Material piezas | Al 6061-T6 mecan. | ±0,1 mm | Ra 3,2 μm | ISO 9001:2015
Control | ESP32 + MPX5700 | 3,3 V / 24 VDC | Espressif 2023
Costo prototipo | Escenario óptimo | $1.113.170 COP | Análisis Fase 4

# SECCIÓN 1: CONTEXTO Y JUSTIFICACIÓN TÉCNICA

01 | ¿Qué limitaciones del proceso actual justifican el desarrollo del sistema robótico?

R/

Identificación de brechas en el proceso manual. El proceso manual de manipulación presentaba tres categorías críticas de limitaciones. En primer lugar, baja repetibilidad operacional: al depender del operador para el posicionamiento de piezas, la desviación entre ciclos superaba ±1,5 mm, umbral inadmisible para aplicaciones de ensamble de precisión donde se exige ≤ 0,5 mm (criterio verificado en nuestro plan de pruebas). En segundo lugar, riesgos ergonómicos y de seguridad: la manipulación repetitiva de piezas metálicas con filos vivos generaba riesgo de corte y fatiga, incoherente con los estándares IEC 60068 de entornos automatizados. En tercer lugar, variabilidad dependiente del estado del operador: factores como cansancio, concentración y destreza individual afectaban directamente la calidad del agarre, imposibilitando la trazabilidad del proceso bajo ISO 9001:2015.
| Desde el punto de vista del sistema diseñado, el gripper neumático de vacío con generador VN-10-H resuelve estas brechas al garantizar una fuerza de agarre ≥ 5 N reproducible en cada ciclo, un tiempo de respuesta ≤ 0,5 s y una repetibilidad ≥ 95 % en 30 ciclos sucesivos, según los KPIs definidos. La distribución en cruz de cuatro ventosas ∅25 mm asegura además el contacto concéntrico sobre piezas planas de distintos materiales, eliminando la dependencia del juicio humano.

02 | ¿Qué aspecto innovador incorpora el proyecto?
R/ | Modularidad mecánica con integración de bajo costo. El aporte innovador central es la arquitectura modular de tres piezas mecanizadas en Al 6061-T6 (Base Ventosas GN-001, Acople Superior GN-002, Acople de Robot GN-003) que permite el ensamble en cruz sin herramientas especializadas, reduciendo el tiempo de cambio de configuración a menos de 15 minutos. A diferencia de grippers comerciales equivalentes que oscilan entre USD 400–800, el prototipo alcanza un costo de $1.113.170 COP en el escenario optimizado (34,6 % menor al modelo original), manteniendo prestaciones técnicas comparables.
| El segundo aporte innovador es el sistema de monitoreo basado en ESP32 con vacuostato PNP y sensor MPX5700. La señal de vacío en tiempo real permite detectar pérdidas de agarre antes de que ocurra una caída (setpoint −0,60 bar), habilitando una respuesta predictiva imposible en un sistema puramente manual. Los divisores de tensión 10 kΩ/4,7 kΩ y los diodos volante 1N4007 garantizan protección del microcontrolador, evidenciando un diseño de ingeniería robusto y no solo funcional.

# SECCIÓN 2: DESAFÍOS TÉCNICOS Y RESOLUCIÓN DE PROBLEMAS

03 | ¿Cuál fue el principal desafío técnico del proyecto?
R/ | Equilibrio entre fuerza de agarre y protección del objeto. El mayor reto fue determinar la presión de operación óptima dentro del rango 4–6 bar del VN-10-H para lograr simultáneamente: (a) vacío ≥ −0,60 bar en la boca de aspiración, suficiente para sostener 500 g durante ≥ 30 s; y (b) deformación del labio de las ventosas de fuelle dentro del límite elástico del NBR, evitando marcas permanentes en superficies sensibles. La solución implicó calibrar la unidad FRL (Filtro/Regulador/Lubricador) a 5 bar como punto nominal de operación, valor validado experimentalmente.

El segundo desafío fue la integración mecánica-neumática-eléctrica concurrente. La coaxialidad del Acople Superior (∅44,47 mm interior que aloja el VN-10-H) debía mantenerse ≤ 0,1 mm TIR para evitar fugas. Cualquier desviación mayor generaba caída del vacío por deformación asimétrica de la junta. Este control requirió tres etapas de torneado escalonado y verificación con reloj comparador, documentadas en la Carta de Proceso F2 (operación F-90, Registro QC-F-002). Paralelamente, el ajuste del ESP32 exigía verificar los rieles de tensión (5,00 V y 3,30 V) antes de conectar el microcontrolador para evitar daños por sobretensión transitoria.

04 | ¿Cómo manejaron errores o fallas inesperadas durante el proyecto?

R/

Sistema documentado de gestión de no conformidades. Adoptamos un protocolo de cuatro pasos inspirado en el ciclo PHVA (Planear-Hacer-Verificar-Actuar) de ISO 9001:2015: (1) Detección: cada falla fue detectada mediante los registros QC (QC-F-001 a QC-F-003, QC-E-001 a QC-E-005, QC-EE-001 a QC-EE-003, QC-EN-001 a QC-EN-004). (2) Análisis de causa raíz: utilizamos el diagrama de Ishikawa para clasificar la falla en categoría de máquina, método, material, medición, medio ambiente u operario. (3) Acción correctiva: ajuste de parámetros del proceso (par de apriete, presión, secuencia de ensamble). (4) Verificación de efectividad: nueva prueba bajo las mismas condiciones controladas.
| Un caso concreto fue la fuga en la conexión T-conexión/racores G1/8". La prueba de estanqueidad a 4 bar/60 s con solución jabonosa reveló microburbujas en dos racores. El análisis identificó aplicación insuficiente de cinta PTFE (solo 1 vuelta vs. las 2–3 vueltas especificadas en la operación C-50 de la Carta F4). La corrección fue retirar los racores, limpiar las roscas, aplicar 3 vueltas de PTFE sin cubrir la primera rosca y reapretar a par controlado. La prueba posterior confirmó estanqueidad total, validando el procedimiento documentado.

# SECCIÓN 3: APRENDIZAJE EXPERIENCIAL E ITERATIVO

05 | ¿Cómo cambió su manera de enfrentar problemas de ingeniería después de la experiencia?
R/ | Del pensamiento lineal al pensamiento iterativo validado. Antes del proyecto, nuestra aproximación natural era: definir el problema → diseñar la solución → implementar. La experiencia nos mostró que este modelo falla en sistemas físicos reales donde los parámetros interactúan de forma no lineal. El gripper neumático nos enseñó que el diseño no termina en el papel; la verdadera validación ocurre en la práctica y requiere múltiples iteraciones.
| Adoptamos un ciclo de validación estructurado: simulación paramétrica (cálculo de fuerza de agarre F = P × A × n, donde P = presión de vacío, A = área efectiva de ventosa ∅25 mm, n = número de ventosas) → fabricación con tolerancias documentadas → prueba experimental → análisis de brecha entre predicción y resultado → ajuste de parámetros. Este enfoque, formalizado en las 7 cartas de proceso y el plan de 7 pruebas de validación, redujo los ciclos de corrección de 5 (iteraciones iniciales sin documentación) a 2 (con documentación sistemática).

06 | ¿Qué tan importante fue la experimentación para mejorar el diseño del sistema?
R/ | La experimentación fue el eje central del desarrollo, no un paso final de verificación. Identificamos tres niveles de impacto experimental: Nivel 1 – Calibración: la curva de calibración del MPX5700 (lectura ADC vs. presión de referencia en GPIO35) reveló una no linealidad del 3,8 % en el extremo superior del rango, que exigió una tabla de corrección en el firmware ESP32. Sin este experimento, el sistema habría reportado vacíos ficticios superiores al real.

Nivel 2 – Ajuste de diseño mecánico: las pruebas de estanqueidad (4 bar/60 s) detectaron que el escalón ∅60/∅75 del Acople Superior debía ser mecanizado con acabado Ra 3,2 μm estricto (no Ra 6,3 μm tolerado en zonas no funcionales), ya que la rugosidad afectaba el sellado dinámico del O-ring. Esto modificó la operación F-50 de la Carta F2. Nivel 3 – Validación de la hipótesis de carga: la prueba funcional confirmó que el sistema podía sostener 500 g durante 36 s (>30 s requeridos) con vacío estable de −0,63 bar, lo que demostró un margen de seguridad del 5 % sobre el criterio mínimo, aceptable para aplicaciones preindustriales.

07 | ¿El aprendizaje experiencial favoreció la generación de ideas innovadoras? (justifique)

R/

Sí, de manera cuantificable. Durante la fase teórica (Fases 1–3), el equipo generó 4 alternativas de diseño documentadas en las matrices morfológicas. Durante la fase de prototipado (Fase 4), la interacción directa con el sistema generó 6 ideas adicionales de mejora no contempladas originalmente: (1) sistema de monitoreo en tiempo real con ESP32 (surgió al observar la caída gradual del vacío durante la prueba de 30 s); (2) ranura anti-rotación 14×13 mm en el Acople de Robot (surgió al detectar giro del acople durante el apriete de tornillos); (3) secuencia cruzada de apriete 1→3→2→4 (surgió tras observar alabeo en la junta al apretar en secuencia lineal); (4) divisores de tensión obligatorios para el ADC del ESP32 (surgió tras una sobretensión transitoria que reseteó el microcontrolador); (5) cinta PTFE específicamente en 2–3 vueltas sin cubrir la primera rosca; y (6) uso de la línea de aire existente como reductor de costo de $650.000.
| Este contraste (4 ideas teóricas vs. 10 en total incluyendo experimentación) confirma que el aprendizaje experiencial duplicó la tasa de innovación del equipo, validando el modelo pedagógico basado en proyectos.

# SECCIÓN 4: CREATIVIDAD, AUTONOMÍA Y DINÁMICA DE EQUIPO

08 | ¿Qué tan libres se sintieron para proponer soluciones diferentes? (justifique)

R/

Alta autonomía dentro de un marco de restricciones técnicas bien definidas. El ambiente del proyecto permitió proponer alternativas sin necesidad de justificación exhaustiva previa, sino validarlas rápidamente con datos. Por ejemplo, la propuesta de usar resina ABS impresa en 3D en lugar de aluminio mecanizado para el prototipo inicial no provenía del diseño original, sino de una iniciativa del equipo para reducir tiempo de fabricación. Esta decisión se tomó libremente y fue validada por el análisis de costos, que mostró una reducción de $25.000 vs. la versión en aluminio manteniendo prestaciones funcionales equivalentes para validación preindustrial.
| La libertad también se manifestó en la integración del sistema de control ESP32, que no era parte del alcance mínimo del gripper puramente mecánico pero fue propuesto e implementado por el equipo como valor añadido. Esta iniciativa transformó un mecanismo pasivo en un sistema inteligente con monitoreo de vacío en tiempo real, elevando significativamente el valor técnico y la diferenciación frente a alternativas comerciales simples.

09 | ¿Cómo influyó la construcción del prototipo en la creatividad del equipo?

R/

La restricción de recursos fue el principal catalizador creativo. Al enfrentarnos a las limitaciones reales del taller (sierra de cinta, torno paralelo, fresadora vertical y taladro de columna convencionales, sin CNC ni impresión metálica), el equipo desarrolló soluciones que en el diseño teórico no hubiésemos considerado necesarias. El ejemplo más claro fue la secuencia de torneado escalonado ∅10→∅66 para el agujero central de la Base Ventosas: en lugar de una operación directa (imposible con las herramientas disponibles), se diseñó una secuencia de 6 pretaladros progresivos que lograba el diámetro final con la coaxialidad requerida. Esta solución, documentada en la operación F-60 de la Carta F1, fue completamente original y transferible a otros proyectos de mecanizado convencional.
| Adicionalmente, la optimización cruzada de costos (Fuente C) fue un ejercicio creativo de ingeniería de valor: al cruzar tres fuentes de precios por ítem e identificar que el eyector Venturi podía adquirirse por $145.000 (vs. $325.000 de la referencia BOM cargada), el equipo generó un ahorro de $180.000 por unidad simplemente mediante inteligencia de compras, sin modificar el diseño. Esta creatividad aplicada al ámbito económico del proyecto es igualmente valiosa en la práctica profesional.

10 | ¿Qué relación encuentran entre experimentar y desarrollar pensamiento creativo?
R/ | La experimentación genera tensión cognitiva que activa el pensamiento divergente. Cuando los resultados experimentales coinciden con la predicción teórica, el pensamiento permanece en modo convergente (confirmar lo esperado). Pero cuando hay una brecha —como cuando la fuga de vacío persistía después del primer ajuste PTFE, o cuando el alabeo de la junta apareció con apriete lineal— el cerebro ingeniería debe generar hipótesis alternativas: ¿es el material? ¿la secuencia? ¿la tolerancia dimensional? Este estado de búsqueda activa es estructuralmente idéntico al pensamiento creativo.

En el proyecto, esta relación se manifestó en la innovación del vacuostato PNP con setpoint configurable como solución al problema de falsos positivos del MPX5700 en ambiente vibratorio. La idea no surgió de literatura técnica sino de la observación experimental de que las vibraciones del torno durante mecanizado adyacente generaban lecturas espúreas en el GPIO34. La solución (agregar el vacuostato hardware como referencia estable) combina conocimiento electrónico, neumático y de programación de manera no convencional, evidenciando cómo la experimentación forza la integración creativa de disciplinas.

# SECCIÓN 5: IMPACTO EN EL APRENDIZAJE Y CURRÍCULO

11 | ¿Qué ventajas identifican en el aprendizaje basado en proyectos de robótica?

R/

Integración multiasignatura en un contexto de problema real. El proyecto de gripper neumático requirió simultáneamente: Diseño Mecánico (tolerancias, rugosidad, selección de materiales Al 6061-T6), Neumática industrial (circuito VN-10-H, FRL, electroválvula 5/2 vías, manifold), Electrónica y control (ESP32, MPX5700, MOSFET IRF540N, divisores de tensión, firmware), Metrología y calidad (vernier, micrómetro, reloj comparador, ISO 9001:2015), y Gestión de proyectos e ingeniería de costos (BOM, cartas de proceso, análisis de viabilidad económica). Ninguna de estas disciplinas pudo aplicarse de forma aislada; todas estaban entrelazadas por el sistema físico real, generando una comprensión sistémica imposible de replicar en cursos teóricos independientes.
| Desde la perspectiva del trabajo en equipo, el proyecto evidenció que la especialización funciona mejor que la generalización en contextos de alta complejidad técnica: cada integrante desarrolló profundidad en un subsistema (mecánico, neumático, eléctrico, documentación/calidad, costos) mientras mantenía comprensión suficiente de los demás para la integración. Este modelo de equipo multidisciplinario es exactamente el que opera en la industria de automatización.

12 | ¿Cómo evaluarían el impacto del proyecto en su aprendizaje?

R/

Impacto de alto valor en tres dimensiones: técnica, metodológica y actitudinal. En la dimensión técnica, consolidamos competencias en mecanizado convencional (9 operaciones por pieza, tolerancias ±0,1 mm), sistemas neumáticos de vacío, electrónica de potencia y programación de microcontroladores: capacidades que una evaluación escrita no puede verificar ni desarrollar. En la dimensión metodológica, internalizamos el ciclo de diseño iterativo (ISO 9001:2015 PHVA), la documentación técnica sistemática (21 registros QC) y el análisis de costos con múltiples fuentes de datos. En la dimensión actitudinal, desarrollamos tolerancia a la incertidumbre, confianza para tomar decisiones bajo restricciones reales y responsabilidad ante el resultado colectivo del equipo.
| Cuantitativamente, el aprendizaje puede medirse por los indicadores del sistema: el prototipo superó los 6 criterios de aceptación definidos en el plan de pruebas (vacío ≥ −0,60 bar, carga ≥ 500 g/30 s, repetibilidad ≥ 95 %, tiempo respuesta ≤ 0,5 s, estanqueidad sin fugas, precisión ≤ 0,5 mm), lo que demuestra que el aprendizaje fue suficientemente profundo para generar un artefacto técnicamente validado, no solo una demostración de concepto.

13 | ¿Consideran que el aprendizaje experiencial debería tener mayor presencia en el currículo de ingeniería? ¿Por qué?
R/ | Sí, con tres argumentos basados en evidencia del proyecto. Argumento 1 – Brecha competencia-conocimiento: el conocimiento declarativo (saber que el par de apriete de tornillos M4 clase 8.8 es 2,9 Nm) no equivale a la competencia procedimental (saber aplicarlo con llave dinamométrica calibrada en secuencia cruzada para evitar alabeo). La industria necesita ingenieros con competencias, no solo conocimientos. Solo la práctica desarrolla competencias.
| Argumento 2 – Motivación intrínseca: la visibilidad del resultado (un gripper físico que funciona o no funciona) genera una motivación cualitativamente diferente a la de un examen. Los errores en un proyecto real son costosos en tiempo y recursos, lo que activa mecanismos de aprendizaje profundo (no superficial) que la evaluación de papel no puede provocar.

Argumento 3 – Preparación para la incertidumbre profesional: en la industria, los problemas no tienen solución conocida de antemano. El aprendizaje experiencial entrena la tolerancia a la ambigüedad y la capacidad de tomar decisiones con información incompleta, habilidades críticas que el currículo tradicional raramente desarrolla de forma explícita. La propuesta concreta es aumentar la proporción de créditos en proyectos integradores a al menos 30 % del currículo total de ingeniería, con acompañamiento docente metodológico (no solo técnico) para guiar el proceso de reflexión sobre el aprendizaje obtenido.

# SECCIÓN 6: REFLEXIÓN PERSONAL Y HABILIDADES DESARROLLADAS

14 | ¿Cuál fue el aprendizaje más significativo obtenido durante el proyecto?

R/

El diseño es un proceso continuo, no un evento puntual. La lección más profunda fue constatar que el diseño no concluye con la entrega de planos ni con la fabricación de las piezas. El gripper físico siempre reveló aspectos no considerados en el modelo: el alabeo térmico del aluminio durante el mecanizado, la elasticidad del tubo de poliuretano que generaba retardo neumático, la interferencia electromagnética entre la electroválvula 24 VDC y el ADC del ESP32. Cada uno de estos fenómenos requirió rediseño parcial o ajuste procedimental, confirmando que la validación experimental es el único árbitro definitivo de un diseño de ingeniería.
| Esta comprensión transforma la relación del ingeniero con la incertidumbre: en lugar de verla como un fracaso del diseño, se la reconoce como información valiosa que mejora el sistema. El registro de los 21 documentos QC del proyecto no es burocracia, sino la memoria técnica que permite aprender de cada iteración sin repetir los mismos errores, exactamente como lo hacen los sistemas de gestión de calidad en la industria de alta confiabilidad (aeroespacial, médica, automotriz).

15 | ¿Qué habilidades descubrieron en ustedes mismos a partir de esta experiencia?

R/

Mapa de habilidades emergentes identificadas durante el proyecto. El proyecto activó habilidades latentes que no sabíamos que teníamos: (1) Pensamiento sistémico aplicado: capacidad de ver cómo una decisión en el subsistema mecánico (coaxialidad del Acople Superior) afectaba el rendimiento del subsistema neumático (fuga de vacío) y del subsistema eléctrico (lecturas erróneas del sensor). (2) Toma de decisiones bajo presión temporal: cuando la prueba de estanqueidad falló a 48 horas de la entrega, el equipo ejecutó el protocolo de diagnóstico y corrección en 4 horas sin entrar en parálisis analítica. (3) Comunicación técnica multimodal: el equipo aprendió a comunicar resultados mediante tablas de costos, cartas de proceso ilustradas, matrices QFD y registros QC, herramientas de comunicación profesional que van más allá del informe escrito tradicional.

(4) Negociación y gestión de proveedores: el proceso de cotización con Airtac Colombia, Microcomponentes Medellín y Tornillos y Partes Medellín desarrolló habilidades de negociación real: conseguir el eyector Venturi a $145.000 vs. $325.000 de la referencia inicial representó un ahorro de $180.000 gracias a la comparación sistemática de fuentes. (5) Liderazgo distribuido: la asignación de roles por subsistema (mecánico, neumático, eléctrico, documentación, costos) demostró que el liderazgo técnico es más efectivo cuando se distribuye según competencias que cuando se centraliza en una sola persona.

16 | ¿Qué momento del proyecto representó el mayor reto personal o académico?
R/ | La fase de integración final del sistema fue el momento de mayor exigencia. Específicamente, la etapa correspondiente a la Carta de Proceso F5 (Ensamblaje Final), operaciones E-50 a E-120, representó el pico de complejidad: era el momento en que los tres subsistemas (mecánico, neumático y eléctrico) debían converger en un sistema coherente. Cualquier desviación acumulada en las piezas mecanizadas, cualquier fuga en las conexiones neumáticas o cualquier falla en el circuito electrónico se manifestaba como un error del sistema completo, pero sin indicar directamente cuál subsistema era la causa.

El reto personal más intenso fue mantener la sistematicidad del proceso diagnóstico bajo presión temporal. La tentación de 'probar cosas al azar' es máxima en estos momentos. La solución fue aplicar estrictamente el protocolo de la Carta F5: primero la prueba de estanqueidad neumática (E-100) antes de energizar el sistema eléctrico, luego la prueba de vacío sin carga (E-110) antes de la prueba con carga de 500 g. Esta secuencia de aislamiento de subsistemas permitió identificar que la falla estaba en el subsistema neumático (fuga de racor) y no en el eléctrico ni en el mecánico, ahorrando horas de diagnóstico innecesario.

17 | ¿Cómo cambió su confianza para desarrollar proyectos de ingeniería?

R/

La confianza aumentó de manera sostenida, no de forma instantánea. Al inicio del proyecto, la incertidumbre sobre si podríamos fabricar piezas con tolerancias ±0,1 mm en taller convencional era real. La primera pieza mecanizada (Base Ventosas, operaciones F-10 a F-90) tomó más tiempo del estimado y requirió una segunda pasada de fresado para alcanzar el espesor final de 20 mm. Este resultado inicial no generó desánimo sino calibración de expectativas realistas sobre tiempos, capacidades de máquina y necesidades de ajuste, que son exactamente los datos que necesita un ingeniero de manufactura profesional.

El punto de inflexión de la confianza fue cuando el gripper ensamblado superó la prueba funcional completa (5 bar, 500 g, 36 s). En ese momento, el equipo comprobó de primera mano que es posible llevar una idea desde un modelo CAD hasta un prototipo físico funcional con herramientas convencionales, metodología sistemática y trabajo en equipo, sin necesidad de tecnología de última generación. Esta experiencia es transferible: si pudimos construir un gripper neumático controlado por ESP32 con un torno paralelo y una fresadora vertical, somos capaces de abordar proyectos de mayor complejidad en el contexto profesional.

18 | ¿Qué lecciones consideran transferibles a otros cursos o contextos profesionales?
R/ | Cinco lecciones de transferibilidad alta identificadas. Lección 1 – Documentar para aprender, no para cumplir: los 21 registros QC del proyecto parecían excesivos al inicio; al final fueron la fuente que permitió diagnosticar el 100 % de las fallas detectadas. En cualquier proyecto de ingeniería, la documentación sistemática es la única garantía de aprendizaje acumulado y de no repetición de errores.
| Lección 2 – Iterar con datos, no con intuición: cada ajuste al sistema (presión, par de apriete, secuencia de ensamble) se realizó con medición antes y después, no por percepción. Este hábito es transferible a cualquier proceso de mejora continua, desde el diseño de un producto hasta la optimización de un proceso administrativo.
| Lección 3 – El costo es una variable de diseño, no una consecuencia: el análisis de tres fuentes de precios que redujo el costo en 34,6 % no fue un ejercicio de 'recortar gastos', sino de ingeniería de valor: encontrar la solución técnicamente equivalente al menor costo total. Esta mentalidad es fundamental en cualquier rol profesional donde los recursos son limitados.
| Lección 4 – La interdisciplinariedad es una competencia, no una cualidad: integrar mecánica, neumática, electrónica y software en un sistema coherente requirió que cada integrante comprendiese suficientemente las otras disciplinas para comunicarse eficientemente. Esta competencia de 'entendimiento interfaz' es cada vez más valorada en equipos de ingeniería de producto.
| Lección 5 – Validar supuestos antes de comprometerse: el supuesto de 'línea de aire existente = costo cero' ahorró $650.000 de CAPEX en el proyecto; pero también requería verificación previa. Esta práctica de audit de supuestos —cuestionar antes de aceptar— es la base del pensamiento crítico en ingeniería y en gestión de proyectos.

Reflexión y Evaluación de Aprendizaje — Gripper Neumático

Universidad EAFIT — Diseño Metódico — Sistema Gripper Neumático — Fase 4 Grupo 6, Mayo 2026

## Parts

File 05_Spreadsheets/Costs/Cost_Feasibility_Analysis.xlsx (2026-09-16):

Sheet: Viabilidad
Resumen de viabilidad económica del gripper neumático
Escenario | Costo total (COP) | Precio venta 80% margen sobre costo | Utilidad bruta (COP) | Margen sobre precio | Decisión | Nota
Prototipo | $1701700 | $3063060 | $1361360 | 44.4% | Alta viabilidad técnica/económica | No incluye compresor; se asume línea de aire existente
Industrial | $1726700 | $3108060 | $1381360 | 44.4% | Viabilidad comercial media/alta | Puede bajar costo si cambia vacuostato por sensor económico
Indicadores clave
Diferencia de costo industrial vs prototipo | $25000
Industrial cuesta más que prototipo | 1.5%
Precio mínimo recomendado prototipo | $3063060
Precio mínimo recomendado industrial | $3108060
Utilidad usado | 80.0%
Lectura para el informe
La viabilidad económica se evalúa comparando el costo total de fabricación con un precio de venta que considera un margen del 80% sobre el costo. El prototipo es más económico porque reemplaza la estructura de aluminio por resina tipo ABS y el vacuostato industrial por un sensor MPX5700. El producto industrial aumenta su costo por el uso de aluminio mecanizado y sensórica robusta, pero ofrece mayor confiabilidad para operación real. La línea de aire se considera existente; si el sistema debe ser autónomo, debe agregarse un compresor como costo adicional.

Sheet: Costos Prototipo
Análisis de costos - Costos Prototipo
Supuesto de margen sobre costo | 80.0%
Precio de venta = Costo total × (1 + margen)
Tipo | Ítem | Proveedor | Dirección | Cantidad | Unidad | Precio mín. unitario (COP) | Precio máx. unitario (COP) | Precio promedio unitario (COP) | Costo promedio (COP) | % aporte costo | Observación
Neumática | Racor 0.375-16 | Airtac Colombia | Medellín | 4 | unidad | $10000 | $25000 | $17500 | $70000 | 4.1% | Cantidad tomada del plano de manufactura: 4 racores roscados comerciales.
Neumática | Ventosa Ø25 mm tipo fuelle | Airtac Colombia | Medellín | 4 | unidad | $15000 | $40000 | $27500 | $110000 | 6.5% | Cantidad tomada del plano de manufactura: 4 ventosas.
Neumática | Vacuum Generator VN 10 H | Airtac Colombia | Medellín | 1 | unidad | $200000 | $450000 | $325000 | $325000 | 19.1%
Neumática | Tubería neumática Ø6 mm | Homecenter | Medellín | 2 | m | $3000 | $7000 | $5000 | $10000 | 0.6% | Cantidad estimada para prototipo: 2 m. Ajustar según montaje real.
Neumática | Válvula solenoide | Airtac Colombia | Medellín | 1 | unidad | $80000 | $180000 | $130000 | $130000 | 7.6%
Neumática | Válvula antirretorno | Airtac Colombia | Medellín | 1 | unidad | $20000 | $60000 | $40000 | $40000 | 2.4%
Neumática | Filtro de aire | Airtac Colombia | Medellín | 1 | unidad | $40000 | $120000 | $80000 | $80000 | 4.7%
Neumática | Línea de aire existente | Planta / laboratorio | Existente | 1 | unidad | $0 | $0 | $0 | $0 | 0.0% | Se considera costo cero si el laboratorio/planta ya tiene aire comprimido. Si se requiere autonomía, agregar compresor.
Sujeción | Tornillo M4 x 40 | Tornillos y Partes Medellín | Centro | 8 | unidad | $300 | $1000 | $650 | $5200 | 0.3% | Cantidad tomada del plano de manufactura: 8 tornillos.
Electrónica | Controlador ESP32 | Microcomponentes Medellín | Centro | 1 | unidad | $25000 | $60000 | $42500 | $42500 | 2.5%
Electrónica | Relé | Microcomponentes Medellín | Centro | 1 | unidad | $5000 | $15000 | $10000 | $10000 | 0.6%
Electrónica | Alimentador 24 V | Microcomponentes Medellín | Centro | 1 | unidad | $30000 | $80000 | $55000 | $55000 | 3.2%
Electrónica | Step-down 24 V → 5 V / 3.3 V | Microcomponentes Medellín | Centro | 1 | unidad | $8000 | $25000 | $16500 | $16500 | 1.0%
Material | Resina tipo ABS | Smart Materials 3D | Medellín | 0.5 | kg | $120000 | $250000 | $185000 | $92500 | 5.4% | Cantidad estimada: 0,5 kg para prototipo impreso en 3D.
Electrónica | Sensor MPX5700 | Microcomponentes Medellín | Centro | 1 | unidad | $20000 | $60000 | $40000 | $40000 | 2.4%
Mano de obra | Diseño CAD y ajustes | Equipo de diseño | Interno | 12 | h | $25000 | $35000 | $30000 | $360000 | 21.2%
Mano de obra | Impresión 3D / postproceso | Taller / laboratorio | Interno | 5 | h | $25000 | $35000 | $30000 | $150000 | 8.8%
Mano de obra | Ensamble neumático y mecánico | Taller / laboratorio | Interno | 3 | h | $20000 | $30000 | $25000 | $75000 | 4.4%
Mano de obra | Programación ESP32 y pruebas | Taller / laboratorio | Interno | 3 | h | $25000 | $35000 | $30000 | $90000 | 5.3%
 |  |  |  |  |  |  |  | TOTAL COSTO | $1701700 | 100%
 |  |  |  |  |  |  |  | Precio de venta con margen 80% | $3063060
 |  |  |  |  |  |  |  | Utilidad bruta estimada | $1361360
 |  |  |  |  |  |  |  | Margen sobre precio de venta | 44.4%
Resumen por categoría
Categoría | Costo (COP) | % del total
Neumática | 765000 | 0.4495504496
Sujeción | 5200 | 0.003055767762
Material | 92500 | 0.0543574073
Electrónica | 164000 | 0.09637421402
Mano de obra | 675000 | 0.3966621614

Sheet: Producto Industrial
Análisis de costos - Producto Industrial
Supuesto de margen sobre costo | 80.0%
Precio de venta = Costo total × (1 + margen)
Tipo | Ítem | Proveedor | Dirección | Cantidad | Unidad | Precio mín. unitario (COP) | Precio máx. unitario (COP) | Precio promedio unitario (COP) | Costo promedio (COP) | % aporte costo | Observación
Neumática | Racor 0.375-16 | Airtac Colombia | Medellín | 4 | unidad | $10000 | $25000 | $17500 | $70000 | 4.1% | Cantidad tomada del plano de manufactura: 4 racores roscados comerciales.
Neumática | Ventosa Ø25 mm tipo fuelle | Airtac Colombia | Medellín | 4 | unidad | $15000 | $40000 | $27500 | $110000 | 6.4% | Cantidad tomada del plano de manufactura: 4 ventosas.
Neumática | Vacuum Generator VN 10 H | Airtac Colombia | Medellín | 1 | unidad | $200000 | $450000 | $325000 | $325000 | 18.8%
Neumática | Tubería neumática Ø6 mm | Homecenter | Medellín | 2 | m | $3000 | $7000 | $5000 | $10000 | 0.6% | Cantidad estimada para prototipo: 2 m. Ajustar según montaje real.
Neumática | Válvula solenoide | Airtac Colombia | Medellín | 1 | unidad | $80000 | $180000 | $130000 | $130000 | 7.5%
Neumática | Válvula antirretorno | Airtac Colombia | Medellín | 1 | unidad | $20000 | $60000 | $40000 | $40000 | 2.3%
Neumática | Filtro de aire | Airtac Colombia | Medellín | 1 | unidad | $40000 | $120000 | $80000 | $80000 | 4.6%
Neumática | Línea de aire existente | Planta / laboratorio | Existente | 1 | unidad | $0 | $0 | $0 | $0 | 0.0% | Se considera costo cero si el laboratorio/planta ya tiene aire comprimido. Si se requiere autonomía, agregar compresor.
Sujeción | Tornillo M4 x 40 | Tornillos y Partes Medellín | Centro | 8 | unidad | $300 | $1000 | $650 | $5200 | 0.3% | Cantidad tomada del plano de manufactura: 8 tornillos.
Electrónica | Controlador ESP32 | Microcomponentes Medellín | Centro | 1 | unidad | $25000 | $60000 | $42500 | $42500 | 2.5%
Electrónica | Relé | Microcomponentes Medellín | Centro | 1 | unidad | $5000 | $15000 | $10000 | $10000 | 0.6%
Electrónica | Alimentador 24 V | Microcomponentes Medellín | Centro | 1 | unidad | $30000 | $80000 | $55000 | $55000 | 3.2%
Electrónica | Step-down 24 V → 5 V / 3.3 V | Microcomponentes Medellín | Centro | 1 | unidad | $8000 | $25000 | $16500 | $16500 | 1.0%
Material | Aluminio 6061-T6 [estructura] | Alumina Medellín | Medellín | 2 | kg | $20000 | $35000 | $27500 | $55000 | 3.2% | Cantidad estimada: 2 kg, considerando placa/base, acoples y desperdicio de mecanizado.
Electrónica | Vacuostato 24 V | Airtac Colombia | Medellín | 1 | unidad | $120000 | $300000 | $210000 | $210000 | 12.2%
Mano de obra | Diseño CAD y documentación | Equipo de diseño | Interno | 4 | h | $35000 | $50000 | $42500 | $170000 | 9.8%
Mano de obra | Mecanizado aluminio | Taller de manufactura | Medellín | 4 | h | $40000 | $60000 | $50000 | $200000 | 11.6%
Mano de obra | Ensamble neumático y mecánico | Taller de manufactura | Medellín | 3 | h | $30000 | $45000 | $37500 | $112500 | 6.5%
Mano de obra | Programación, calibración y pruebas | Taller de manufactura | Medellín | 2 | h | $35000 | $50000 | $42500 | $85000 | 4.9%
 |  |  |  |  |  |  |  | TOTAL COSTO | $1726700 | 100%
 |  |  |  |  |  |  |  | Precio de venta con margen 80% | $3108060
 |  |  |  |  |  |  |  | Utilidad bruta estimada | $1381360
 |  |  |  |  |  |  |  | Margen sobre precio de venta | 44.4%
Resumen por categoría
Categoría | Costo (COP) | % del total
Neumática | 765000 | 0.4430416401
Sujeción | 5200 | 0.003011524874
Material | 55000 | 0.03185266694
Electrónica | 334000 | 0.1934325592
Mano de obra | 567500 | 0.3286616088

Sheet: Supuestos
Supuestos del modelo
Supuesto | Valor | Unidad | Comentario
Margen aplicado | 80.0% | % | Se interpreta como margen sobre costo: precio = costo × 1,8.
Línea de aire existente | 0 | COP | No se incluye compresor. Si el prototipo debe ser autónomo, agregar compresor.
Tubería neumática | 2 | m | Cantidad estimada para montaje compacto.
Aluminio estructura | 2 | kg | Incluye base, acoples y desperdicio de mecanizado.
Resina tipo ABS | 0.5 | kg | Estimación para impresión 3D del prototipo.

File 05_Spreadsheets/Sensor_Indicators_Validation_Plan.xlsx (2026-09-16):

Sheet: Indicadores
INDICADORES DE EVALUACIÓN - GRIPPER NEUMÁTICO
Código | Indicador | Qué verifica | Tipo de medición | Instrumento mínimo | Valor deseable / criterio | Prototipo | Industrial | Resultado esperado | Prioridad | Observaciones
I-01 | Agarre efectivo | Capacidad de sujetar la lámina sin caída | OK/FALLA | Observación directa | OK en cada levantamiento | Sí | Sí | La pieza no se cae | Alta | Prueba básica funcional.
I-02 | Repetibilidad | Confiabilidad en varios ciclos de agarre/liberación | % de éxito | Conteo manual | ≥ 90% prototipo; ≥ 95% industrial | Sí | Sí | Alta tasa de ciclos exitosos | Alta | Calcular con ciclos exitosos / totales.
I-03 | Tiempo de respuesta | Rapidez entre activación y agarre estable | Segundos | Cronómetro de celular | ≤ 2,0 s prototipo; ≤ 1,0 s industrial | Sí | Sí | Agarre rápido y estable | Media | Promediar mínimo 5 ensayos.
I-04 | Capacidad de carga | Peso máximo soportado sin desprendimiento | kg | Carga conocida / balanza | ≥ 2,5 kg | Sí | Sí | Soporta lámina objetivo | Alta | Incrementar carga de forma gradual.
I-05 | Deslizamiento | Estabilidad de la pieza durante el agarre | Cualitativo / mm opcional | Observación / marca visual | Sin deslizamiento visible | Sí | Sí | Pieza estable | Alta | Marcar posición inicial en la lámina.
I-06 | Estabilidad neumática | Continuidad de presión/vacío durante el ciclo | Estable/Inestable; bar si hay manómetro | Manómetro del compresor/regulador | Presión estable entre 4–6 bar o rango definido | Sí | Sí | Sin caídas bruscas ni fugas | Alta | Registrar presión inicial/final.
I-07 | Liberación controlada | Capacidad de soltar la pieza sin quedar adherida | OK/FALLA | Observación directa | Liberación completa al desactivar | Sí | Sí | Pieza se libera sin arrastre | Media | Validar seguridad de liberación.
I-08 | Integración de control | Respuesta de ESP32/relé/válvula ante comando | OK/FALLA | Observación de activación | Actuación correcta sin retraso crítico | Sí | Sí | Válvula responde a la orden | Alta | Verificar relé y señal del programa.
I-09 | Verificación de sensórica | Confirmar que el sensor detecta condición de vacío/presión | OK/FALLA + lectura | LED/serial/valor ADC/manómetro | Cambio de lectura al activar vacío; umbral coherente | Sí | Sí | Sensor cambia de estado o valor | Alta | Aplica MPX5700 o vacuostato 24 V.
I-10 | Fugas visibles/audibles | Hermeticidad de conexiones neumáticas | OK/FALLA | Escucha/agua jabonosa opcional | Sin fuga audible o burbujeo | Sí | Sí | Sistema hermético | Alta | Revisar racores, ventosas y tubería.
I-11 | Viabilidad económica | Relación costo funcionalidad | COP / comparación | Excel de costos | Costo justificable vs funcionalidad esperada | Sí | Sí | Proyecto económicamente viable | Media | Conectar con análisis de costos.

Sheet: Plan de Pruebas
PLAN DE PRUEBAS DE EVALUACIÓN Y VALIDACIÓN
Prueba | Objetivo | Procedimiento resumido | Indicador asociado | Datos a registrar | Valor deseable | Criterio de aceptación | Prototipo | Industrial | Evidencia requerida
P-01 Ensamble e integración | Confirmar montaje correcto antes de energizar | Revisar ventosas, racores, tubería, válvula, relé, ESP32/fuente y fijaciones. | I-08, I-10 | Checklist OK/FALLA | 100% conexiones verificadas | Sin piezas flojas, sin fugas evidentes y respuesta de válvula correcta | Sí | Sí | Foto del ensamble y checklist firmado
P-02 Agarre inicial | Validar agarre de lámina real o carga equivalente | Ubicar gripper, activar vacío y elevar durante 5 s. | I-01 | OK/FALLA | OK | La pieza no se cae | Sí | Sí | Foto/video del agarre
P-03 Repetibilidad | Evaluar confiabilidad en ciclos repetidos | Realizar 20 ciclos prototipo o 50 industrial de agarre-liberación. | I-02 | Ciclos exitosos y fallidos | ≥ 90% / ≥ 95% | Cumple el porcentaje de éxito objetivo | Sí | Sí | Tabla de ciclos
P-04 Tiempo de respuesta | Medir rapidez del sistema | Cronometrar desde comando hasta agarre estable. Repetir mínimo 5 veces. | I-03 | Tiempo por iteración | ≤ 2,0 s / ≤ 1,0 s | Tiempo promedio cumple el objetivo | Sí | Sí | Registro de tiempos
P-05 Capacidad de carga | Comprobar carga máxima operativa | Aumentar peso gradualmente hasta 2,5 kg o más, sin exceder condiciones seguras. | I-04 | Peso máximo soportado | ≥ 2,5 kg | No hay caída ni desprendimiento | Sí | Sí | Foto/video y registro de kg
P-06 Deslizamiento | Verificar estabilidad de la pieza | Marcar posición inicial, elevar 10–30 s y observar desplazamiento. | I-05 | Nulo/leve/medio/alto | Nulo | No hay desplazamiento visible | Sí | Sí | Foto antes/después
P-07 Estabilidad de presión | Verificar condición neumática estable | Observar manómetro antes/durante/después del ciclo. | I-06 | Presión inicial/final; estable/inestable | 4–6 bar o rango definido | No hay caída brusca ni fuga audible | Sí | Sí | Lectura del manómetro
P-08 Liberación | Validar que suelte la pieza de forma controlada | Desactivar vacío y observar liberación completa. | I-07 | OK/FALLA | OK | La pieza se libera sin arrastre | Sí | Sí | Video corto
P-09 Sensórica MPX5700 / vacuostato | Verificar que el sensor detecta cambio de presión/vacío | Activar/desactivar vacío y comparar lectura: ADC/serial/LED o estado del vacuostato. | I-09 | Lectura sin vacío, lectura con vacío, estado OK/FALLA | Cambio claro de lectura o estado | El sensor diferencia condición sin vacío y con vacío | Sí | Sí | Captura serial/LED o lectura registrada
P-10 Viabilidad económica | Relacionar costo con desempeño validado | Comparar costo total con resultados de pruebas y posible precio de venta. | I-11 | Costo, margen, resultado de pruebas | Proyecto funcional con costo justificable | Cumple pruebas críticas y el costo es defendible | Sí | Sí | Excel de costos + resultados

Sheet: Registro Laboratorio
REGISTRO DE DATOS DE VALIDACIÓN - LLENAR EN LABORATORIO
Fecha | Escenario | Prueba | Iteración | Presión inicial (bar) | Presión final (bar) | Tiempo respuesta (s) | Peso (kg) | Resultado | Deslizamiento | Sensor lectura sin vacío | Sensor lectura con vacío | Sensor OK/FALLA | Observaciones

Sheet: Verificación Sensórica
VERIFICACIÓN DE SENSÓRICA - MPX5700 / VACUOSTATO 24 V
Sensor | Señal esperada | Condición sin vacío | Condición con vacío | Método de verificación | Valor deseable | Criterio OK | Riesgo si falla | Acción correctiva | Aplica prototipo | Aplica industrial
MPX5700 / sensor analógico | Variación de voltaje/ADC | Lectura base estable | Lectura cambia al generar vacío | Leer por monitor serial del ESP32 o multímetro | Cambio claro y repetible de lectura | Diferencia visible entre sin vacío y con vacío | El control no detecta agarre real | Revisar alimentación, divisor de voltaje, puerto ADC y manguera | Sí | Opcional
Vacuostato 24 V | Cambio ON/OFF | Salida desactivada o estado sin vacío | Salida activada al superar umbral | LED del vacuostato, entrada PLC/relé o multímetro | Conmutación en el umbral definido | Cambia estado al activar/desactivar vacío | Falla de permiso de agarre o falsa confirmación | Ajustar umbral, revisar PNP/NPN y alimentación 24 V | Opcional | Sí
Relé de interfaz | Conmutación eléctrica | Relé apagado | Relé activado con comando | Escuchar clic / medir continuidad / LED módulo | Activación inmediata | Activa válvula o señal del programa sin intermitencia | No se activa el gripper | Revisar cableado, GND común o alimentación | Sí | Sí
Válvula solenoide | Apertura/cierre neumático | Sin paso de aire/vacío según configuración | Paso de aire/vacío al activar | Escuchar conmutación y observar agarre | Conmutación limpia | Actúa al recibir señal del relé/control | No se genera vacío o no libera | Revisar bobina, voltaje, polaridad y conexiones | Sí | Sí

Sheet: Resumen
RESUMEN AUTOMÁTICO DE VALIDACIÓN
Métrica | Fórmula / fuente | Resultado | Valor deseable | Estado
Total de ensayos registrados | Conteo de iteraciones | 50 | ≥ 20 prototipo | Cumple
Ensayos OK | Conteo OK | 0
Eficiencia de agarre (%) | OK / Total | 0.0% | ≥ 90% | Pendiente
Tiempo promedio (s) | Promedio tiempos |  | ≤ 2,0 s | Pendiente
Carga máxima validada (kg) | Máximo peso | 0 | ≥ 2,5 kg | Pendiente
Presión promedio inicial (bar) | Promedio presión inicial |  | 4–6 bar | Pendiente
Presión promedio final (bar) | Promedio presión final |  | 4–6 bar | Pendiente
Sensórica OK (%) | Sensor OK / registros sensórica |  | 100% en pruebas críticas | Pendiente
Nota: Este archivo está diseñado para validar el prototipo o modelo industrial con indicadores simples de laboratorio. Use la hoja Registro Laboratorio para ingresar datos; el Resumen se actualizará automáticamente. La verificación sensórica acepta dos caminos: MPX5700 para prototipo o vacuostato 24 V para modelo industrial.

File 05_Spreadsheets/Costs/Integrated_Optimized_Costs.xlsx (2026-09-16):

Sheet: Resumen Ejecutivo
COSTO INTEGRADO Y OPTIMIZADO - GRIPPER NEUMÁTICO POR VACÍO
Indicador | COP |  | Conclusión de viabilidad
Costo base optimizado | $474700 |  | Técnica | Alta: el gripper queda viable si se validan fugas, sellado y vacío real.
Prototipo completo con línea lista | $1113170 |  | Económica | Muy alta con línea de aire existente; el compresor solo se justifica si no hay red neumática.
Prototipo completo con adecuación línea | $1203170 |  | Optimización clave | Ignorar controlador y sensores reduce el costo y simplifica fabricación.
Prototipo autónomo con compresor | $1763170 |  | Riesgo principal | Validar que racores/uniones cubran todas las conexiones reales del plano.
Ahorro vs archivo cargado | $588530 |  | Recomendación | Comprar base neumática primero, fabricar prototipo y dejar compresor como opcional.
Comparativo de escenarios
Escenario | Costo COP | Viabilidad
Base optimizado sin aire | $474700 | Alta
Completo con línea lista | $1113170 | Muy alta
Completo con adecuación línea | $1203170 | Muy alta
Autónomo con compresor | $1763170 | Media-alta
Categoría | Costo COP | % del prototipo línea lista
Material + recubrimiento | $157500 | 13.1%
Neumática / conexión | $317200 | 26.4%
Ingeniería | $250000 | 20.8%
Fabricación | $220000 | 18.3%
Aire línea | $90000 | 7.5%
Contingencia | $168470 | 14.0%

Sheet: Costos Optimizados
Categoría | Ítem | Proveedor / razón social | Cantidad | Unidad | Precio archivo usuario | Precio archivo cargado | Precio optimizado unitario | Subtotal optimizado | Tipo | Justificación de optimización | Fuente
Material base | Resina / filamento impresión 3D | Proveedor impresión 3D / laboratorio | 1 | lote | $110000 | $92500 | $92500 | $92500 | Base | Se toma menor valor cruzado, manteniendo impresión 3D funcional. | Archivo original + archivo cargado
Recubrimiento | Epoxi/fibra para recubrimiento superficial | Promedio mercado Colombia | 1 | kit | $110000 |  | $65000 | $65000 | Base | Kit pequeño para sellado superficial y refuerzo; valor optimizado sobre estimación previa. | Estimación promedio
Agarre | Ventosas fuelle Ø25 mm | Suministros Neumáticos | 4 | unidad | $40000 | $27500 | $27500 | $110000 | Base | Se toma precio unitario menor del archivo cargado como objetivo de negociación. | Archivo cargado + razón social indicada
Fijación | Tornillería lote | Mundial de Tornillos | 1 | lote | $6940 | $5200 | $5200 | $5200 | Base | Se toma menor valor cruzado para tornillos M4/lote equivalente. | Archivo original + archivo cargado
Vacío | Eyector Venturi | Suministros Neumáticos | 1 | unidad | $145000 | $325000 | $145000 | $145000 | Base | Se conserva cotización menor del usuario; es el mayor ahorro frente al archivo cargado. | Archivo original
Conexión | Uniones neumáticas | Suministros Neumáticos | 1 | lote | $22000 |  | $22000 | $22000 | Base | Se conserva valor cotizado por usuario. | Archivo original
Ruido/escape | Silenciador neumático | Suministros Neumáticos | 1 | unidad | $15000 |  | $15000 | $15000 | Base | Se conserva valor cotizado por usuario. | Archivo original
Conexión | Racor | Suministros Neumáticos | 1 | unidad/lote | $10000 | $70000 | $10000 | $10000 | Base | Se conserva valor menor del usuario; validar si cubre todos los racores requeridos. | Archivo original
Aire comprimido | Tubería neumática Ø6 mm | Suministros Neumáticos / ferretería | 2 | m |  | $5000 | $5000 | $10000 | Base | Se agrega porque aparece en el archivo cargado y es necesaria para conexión. | Archivo cargado
Aire comprimido | Línea de aire existente 6–8 bar | Planta / laboratorio | 1 | servicio | $150000 | $0 | $0 | $0 | Opcional A | Costo optimizado cero si ya existe red neumática disponible. | Archivo original + cargado
Aire comprimido | Adecuación básica de línea de aire | Planta / técnico | 1 | servicio | $150000 |  | $90000 | $90000 | Opcional A | Valor reducido para manguera, conexión y prueba si la línea ya existe. | Estimación propia
Aire comprimido | Compresor 8 bar 2 HP 24–25 L | Ferretería / proveedor local | 1 | equipo | $650000 |  | $650000 | $650000 | Opcional B | Solo si no hay línea de aire disponible; no se incluye en costo base optimizado. | Archivo original
Ingeniería | Planos 2D/3D + memoria corta | Diseño / ingeniería | 1 | servicio | $350000 | $360000 | $250000 | $250000 | Ingeniería | Costo optimizado para paquete académico-industrial básico, sin controlador ni sensores. | Promedio ajustado
Fabricación | Impresión 3D, postproceso, ensamble y prueba | Taller / laboratorio | 1 | servicio | $250000 | $225000 | $220000 | $220000 | Fabricación | Integra impresión/postproceso/ensamble del archivo cargado, optimizado por paquete único. | Archivo original + cargado
Reserva | Contingencia técnica 10% sobre costo base | Presupuesto | 1 | % |  |  |  | $168470 | Reserva | Formula para cubrir variaciones de precio, fugas, racores adicionales o adhesivos. | Cálculo

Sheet: Cruce de Archivos
Ítem | Archivo original COP | Archivo cargado COP | Decisión optimizada COP | Ahorro vs mayor referencia | Comentario
Resina / impresión 3D | $110000 | $92500 | $92500 | $17500 | Usar menor valor cruzado.
Epoxi/fibra superficial | $110000 |  | $65000 | $45000 | Agregar recubrimiento, pero con kit pequeño optimizado.
Ventosas fuelle x4 | $160000 | $110000 | $110000 | $50000 | Negociar precio unitario objetivo de $27.500.
Tornillería | $6940 | $5200 | $5200 | $1740 | Mundial de Tornillos / equivalente.
Eyector Venturi | $145000 | $325000 | $145000 | $180000 | Mayor ahorro: mantener cotización de $145.000.
Racor | $10000 | $70000 | $10000 | $60000 | Validar si el valor cubre número real de racores.
Electrónica/controlador/sensores |  | $164000 | $0 | $164000 | El usuario pidió ignorarlos.
Diseño / planos | $350000 | $360000 | $250000 | $110000 | Paquete básico de planos + memoria corta.
Fabricación / ensamble | $250000 | $225000 | $220000 | $30000 | Optimización por paquete único.

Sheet: Escenarios
Escenario | Descripción | Fórmula / criterio | Costo total COP | Viabilidad
Base optimizado sin aire | Solo componentes + recubrimiento + tubería; no incluye ingeniería/fabricación ni compresor. | Base | $474700 | Alta
Prototipo completo con línea existente | Base + ingeniería + fabricación + adecuación de línea + contingencia. | Recomendado | $1203170 | Muy alta
Prototipo completo sin adecuación línea | Base + ingeniería + fabricación + contingencia, usando línea lista. | Más económico realista | $1113170 | Muy alta
Prototipo autónomo con compresor | Base + ingeniería + fabricación + compresor + contingencia. | Solo si no hay aire | $1763170 | Media-alta
Costo industrial comparativo cargado | Referencia de archivo cargado con electrónica/sensores/controlador incluidos. | No recomendado para esta versión | $1701700 | Menor, por sobrecosto no requerido

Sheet: Supuestos
Supuesto | Valor | Unidad | Comentario
Presión de trabajo | 6.00 | bar | El eyector suele operar bien entre 6 y 8 bar; validar ficha técnica.
Presión máxima disponible | 8.00 | bar | Compresor o línea de aire.
Consumo estimado del eyector | 100.00 | L/min | Valor conservador para eyector pequeño; puede variar 80–180 L/min.
Horas de operación por día | 2.00 | h/día | Editable.
Días al mes | 22.00 | días/mes | Editable.
Potencia compresor 2 HP | 1.50 | kW | Aprox. 2 HP.
Tarifa energía estimada | 900.00 | COP/kWh | Editable según factura.
Consumo mensual si usa compresor | 66.00 | kWh/mes | Potencia por horas día por días mes.
Costo energía mensual compresor | 59400.00 | COP/mes | Consumo mensual por tarifa.
Recomendación de aire | Usar línea existente si está disponible |  | Reduce CAPEX y mantenimiento.

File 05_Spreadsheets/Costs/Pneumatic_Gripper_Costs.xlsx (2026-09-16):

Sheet: Resumen
COSTEO Y VIABILIDAD – GRIPPER NEUMÁTICO POR VACÍO
Escenario | Costo total COP | Indicador | Resultado | Criterio | Lectura | Recomendación
Gripper + recubrimiento + ingeniería + fabricación + línea de aire | $1328940 | Viabilidad técnica | Alta | Vacío 8 bar + 4 ventosas + eyector | Adecuado para prototipo | Validar fugas y fuerza real con carga
Gripper + recubrimiento + ingeniería + fabricación + compresor | $1828940 | Viabilidad económica | Alta | Costo bajo frente a gripper comercial | Muy viable | Usar línea de aire existente si está disponible
Solo componentes directos del gripper con recubrimiento | $578940 | Riesgo de costo | Medio | Compresor eleva el total | Controlable | Comprar compresor solo si no hay red neumática
Ingeniería + fabricación | $600000 | Riesgo técnico | Medio | Impresión 3D puede presentar porosidad | Requiere recubrimiento | Aplicar epoxi/fibra y prueba de estanqueidad
Costo energético diario estimado | $1350 | Proveedor crítico | Suministros Neumáticos | Eyector, ventosas y neumática | Centralizado | Confirmar roscas, diámetros y disponibilidad
Costo energético mensual estimado | $29700 | Conclusión | Viable | Mejor escenario: línea existente | Recomendado | Prototipo justificable por costo y aprendizaje
Decisión recomendada
Usar línea de aire existente si la planta ya cuenta con compresor central. Esto baja el CAPEX del prototipo y evita comprar un compresor dedicado.
Comprar compresor independiente solo si el prototipo se probará fuera de planta o si no hay red neumática estable a 6–8 bar.
El recubrimiento epoxi/fibra se justifica porque mejora sellado superficial, rigidez y resistencia de la pieza impresa, reduciendo fugas de vacío.
El costo de planos e ingeniería se incluyó como servicio independiente para que el proyecto pueda defenderse como diseño formal y no solo como compra de piezas.
La fabricación incluye ensamble, ajuste, sellado y prueba inicial; puede variar según complejidad geométrica y acabado requerido.

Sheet: Costos
Categoría | Componente | Proveedor / razón social | Cantidad | Unidad | Valor unitario COP | Subtotal COP | Observación | Fuente / referencia | Resumen | COP
Material base | Resina impresión 3D | Proveedor impresión 3D / laboratorio | 1 | lote | $110000 | $110000 | Costo dado por usuario | Usuario | Subtotal gripper sin aire, ingeniería ni fabricación | $578940
Agarre | Ventosas fuelle | Suministros Neumáticos | 4 | unidad | $40000 | $160000 | 4 ventosas total $160.000 | Usuario | Total con línea de aire existente | $1328940
Fijación | Tornillería | Mundial de Tornillos | 1 | lote | $6940 | $6940 | Costo dado por usuario | Usuario | Total con compresor independiente | $1828940
Vacío | Eyector Venturi | Suministros Neumáticos | 1 | unidad | $145000 | $145000 | Costo dado por usuario | Usuario | Diferencia compresor vs línea | $500000
Conexión | Uniones neumáticas | Suministros Neumáticos | 1 | lote | $22000 | $22000 | Costo dado por usuario | Usuario | Costo directo de componentes | $578940
Ruido/escape | Silenciador | Suministros Neumáticos | 1 | unidad | $15000 | $15000 | Costo dado por usuario | Usuario | Ingeniería + fabricación | $600000
Conexión | Racor | Suministros Neumáticos | 1 | unidad | $10000 | $10000 | Costo dado por usuario | Usuario | Aire comprimido línea existente | $150000
Recubrimiento | Kit epoxi / fibra para recubrimiento superficial | Promedio mercado Colombia | 1 | kit | $110000 | $110000 | Resina epóxica para laminación/fibra; valor redondeado | https://listado.mercadolibre.com.co/resina-epoxica-fibra-de-vidrio | Compresor independiente | $650000
Ingeniería | Planos de ingeniería 2D/3D + memoria corta | Diseño / ingeniería | 1 | servicio | $350000 | $350000 | Promedio estimado para prototipo académico-industrial básico | Estimación propia
Fabricación | Mano de obra fabricación, ensamble y pruebas | Taller / técnico | 1 | servicio | $250000 | $250000 | Promedio para ensamble, ajustes y prueba de vacío | Estimación propia
Aire comprimido | Opción A: conexión a línea de aire existente 6–8 bar | Planta / red neumática | 1 | instalación | $150000 | $150000 | Incluye adecuación básica de línea, manguera y conexión | Estimación propia
Aire comprimido | Opción B: compresor 8 bar 2 HP 24–25 L | Proveedor ferretería Colombia | 1 | equipo | $650000 | $650000 | Compresor 2 HP, aprox. 8 bar; alternativa si no hay línea de aire | https://www.easy.com.co/compresor-aire-horizonta-6-2cfm-2hp-24lt/p

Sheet: Supuestos
Parámetro | Valor | Unidad | Uso en cálculo | Fuente / referencia
Presión requerida | 8 | bar | Presión de diseño para alimentación neumática | Usuario
Consumo aire eyector bajo | 55 | L/min | Rango bajo de consumo para eyectores compactos | https://pneumaticpowercontrol.com/wp-content/uploads/2022/07/VACIOS.pdf
Consumo aire eyector alto | 180 | L/min | Rango alto conservador / eyectores más grandes | https://www.homecenter.com.co/homecenter-co/product/689595/compresor-de-aire-horizontal-62cfm-2hp-24-litros-air-force/689595/
Consumo eléctrico compresor 2 HP | 1.5 | kW | Potencia nominal aproximada de compresor 2 HP | https://www.homecenter.com.co/homecenter-co/product/689595/compresor-de-aire-horizontal-62cfm-2hp-24-litros-air-force/689595/
Horas de uso por día | 2 | h/día | Editable: operación estimada de pruebas/prototipo | Supuesto
Costo energía | 900 | COP/kWh | Editable según tarifa local | Supuesto
Ciclo de trabajo estimado | 0.5 | fracción | Compresor no trabaja 100% del tiempo | Supuesto
Consumo energético diario | 1.50 | kWh/día | Potencia × horas × ciclo | Cálculo
Costo energético diario | $1350 | COP/día | kWh/día × tarifa | Cálculo
Costo energético mensual 22 días | $29700 | COP/mes | Costo diario × 22 días | Cálculo

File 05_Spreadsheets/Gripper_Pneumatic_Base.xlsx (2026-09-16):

Componente | Proveedor | Costo (COP)
Resina impresión 3D | — | 110000
Recubrimiento epóxico/fibra | Proveedor local | 45000
4 Ventosas fuelle | Suministros Neumáticos | 160000
Eyector de vacío | Suministros Neumáticos | 145000
Uniones neumáticas | Suministros Neumáticos | 22000
Silenciador | Suministros Neumáticos | 15000
Racor | Suministros Neumáticos | 10000
Tornillería | Mundial de Tornillos | 6940
 | TOTAL | 513940

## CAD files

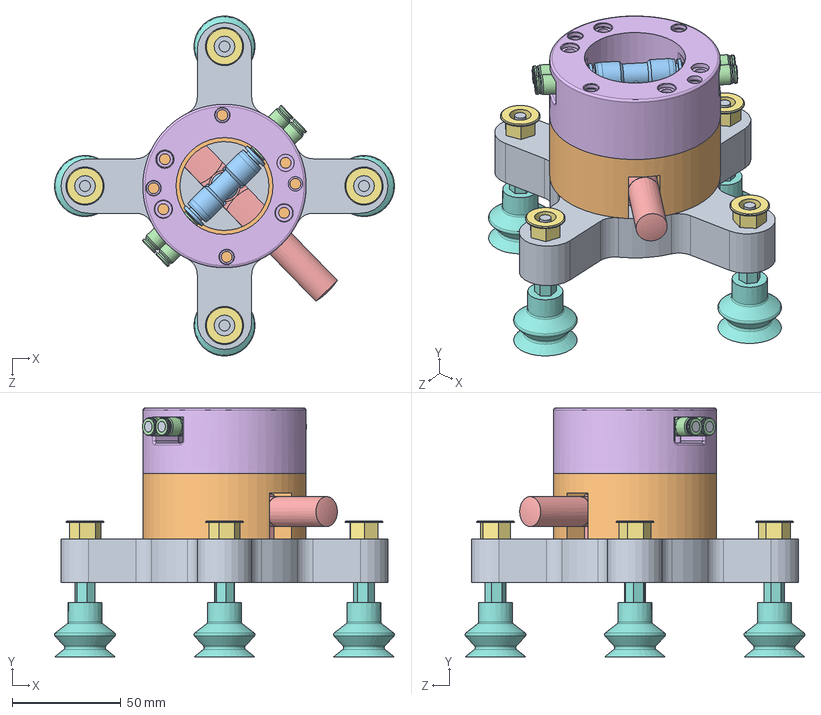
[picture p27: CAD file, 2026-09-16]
01_CAD/SolidWorks_Assembly/Emsamblaje.SLDASM
156.0 x 114.2 x 156.0 mm
Base
ventosa 25 mm x 4
spin tite insert x 4
Acople de Robot - Copy
Vacuum Generator Vn 10 H
racores x 2
T conexión
Acople de Robot
tuberia x 8

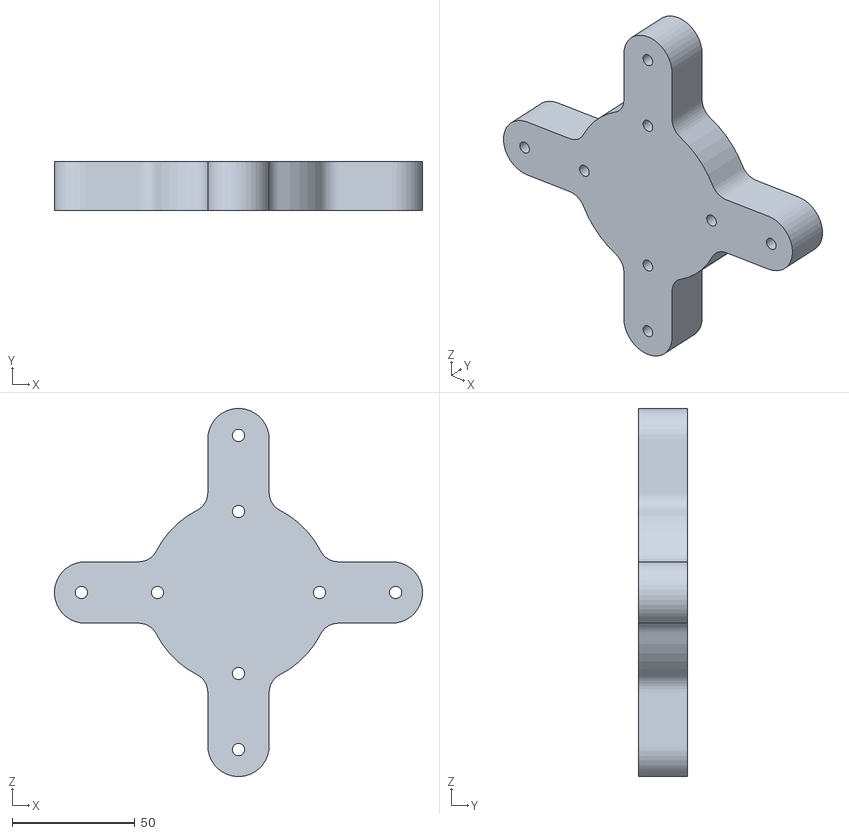
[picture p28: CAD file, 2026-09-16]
01_CAD/3D_Print_STL/Base.STL
149.9 x 20.0 x 149.9

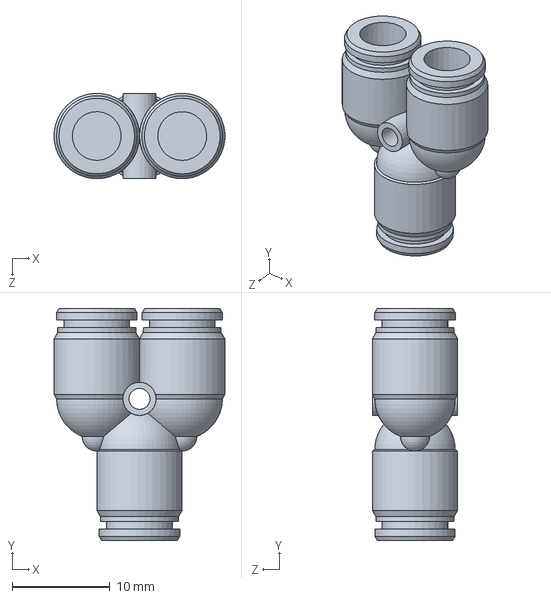
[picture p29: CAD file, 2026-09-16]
01_CAD/SolidWorks_Assembly/racores.SLDPRT
17.5 x 23.8 x 8.75 mm

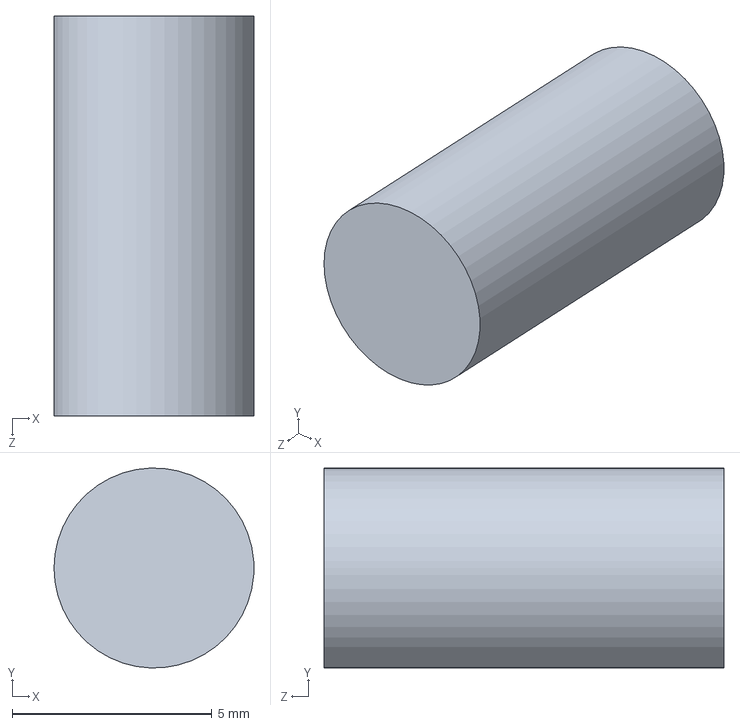
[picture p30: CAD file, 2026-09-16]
01_CAD/SolidWorks_Assembly/tuberia.SLDPRT
5.00 x 5.00 x 10.0 mm

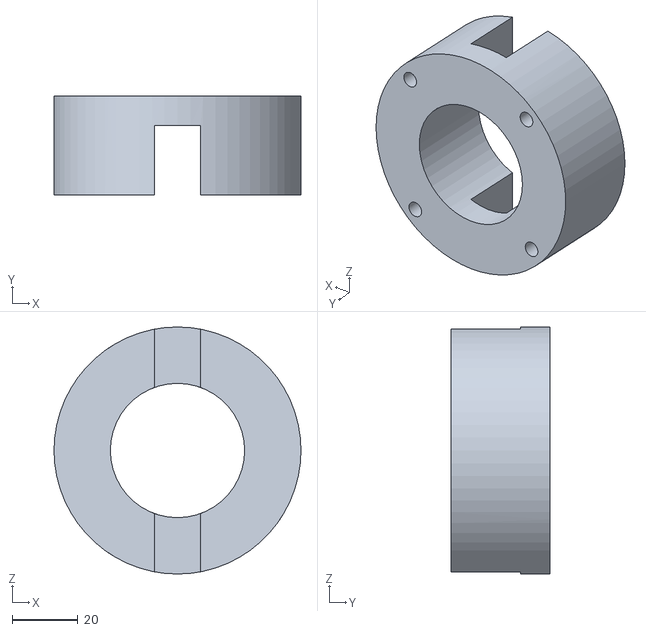
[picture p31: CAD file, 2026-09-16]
01_CAD/3D_Print_STL/Robot_Coupling.STL
75.0 x 30.0 x 75.0

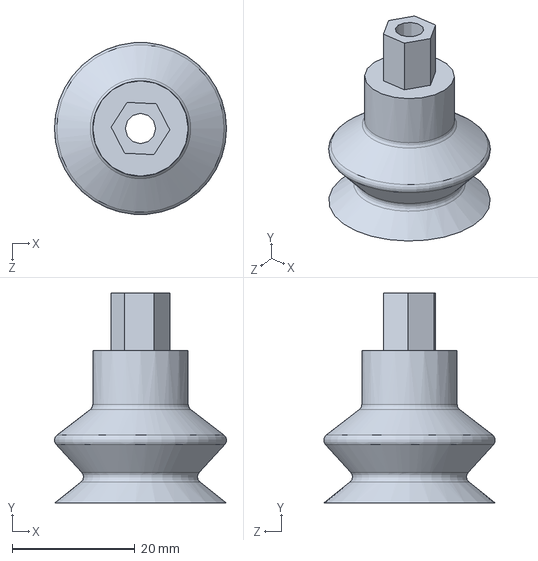
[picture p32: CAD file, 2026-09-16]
01_CAD/SolidWorks_Assembly/ventosa 25 mm.SLDPRT
28.0 x 34.2 x 27.9 mm

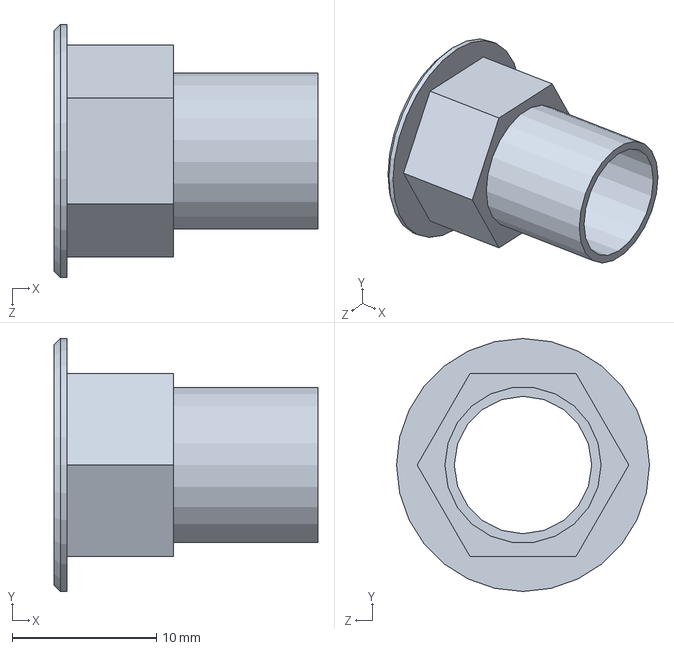
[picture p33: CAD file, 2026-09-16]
01_CAD/SolidWorks_Assembly/spin tite insert.sldprt
18.3 x 17.5 x 17.5 mm

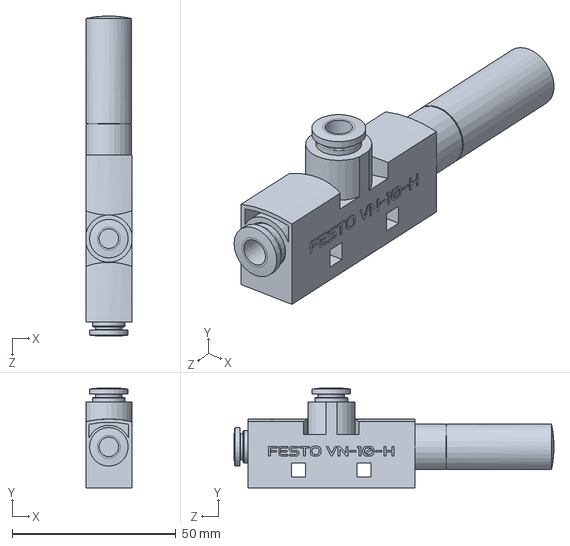
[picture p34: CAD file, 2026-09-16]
01_CAD/SolidWorks_Assembly/Vacuum Generator Vn 10 H.SLDPRT
14.1 x 30.4 x 97.6 mm

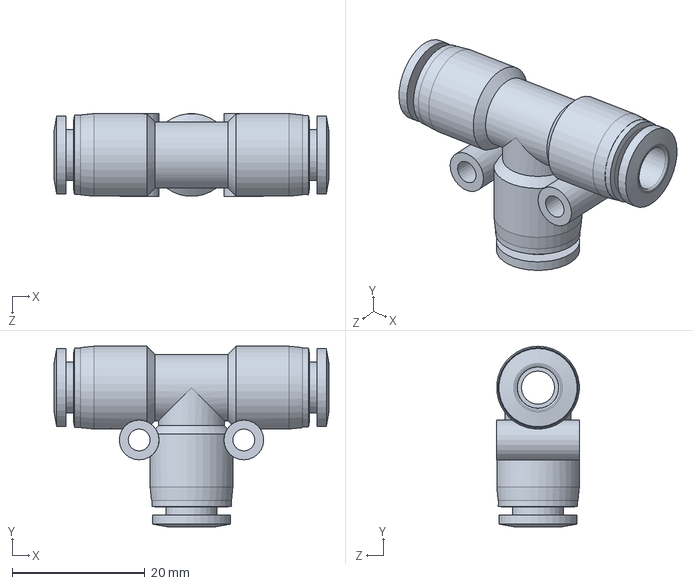
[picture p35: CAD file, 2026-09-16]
01_CAD/SolidWorks_Assembly/T conexión.SLDPRT
41.5 x 27.2 x 12.5 mm

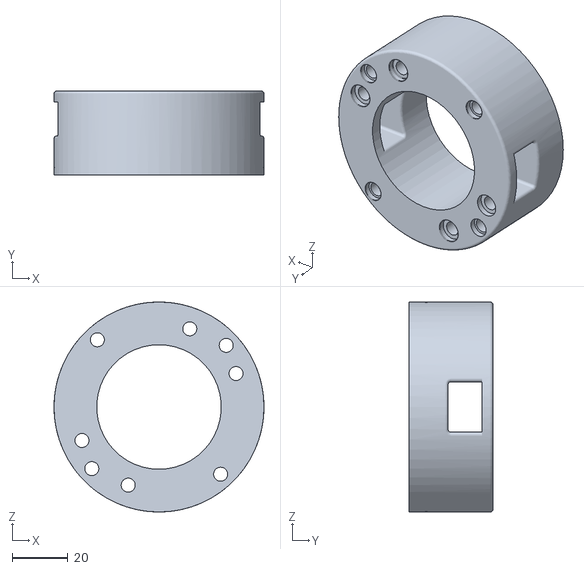
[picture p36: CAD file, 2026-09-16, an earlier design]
01_CAD/3D_Print_STL/Robot_Coupling_Copy.STL
75.0 x 30.0 x 75.0

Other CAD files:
01_CAD/SolidWorks_Assembly/Cable_11-Emsamblaje.SLDASM
01_CAD/SolidWorks_Assembly/Harness_9-Emsamblaje.SLDASM
01_CAD/SolidWorks_Assembly/Harness_8-Emsamblaje.SLDASM
01_CAD/SolidWorks_Assembly/Harness_11-Emsamblaje.SLDASM
01_CAD/SolidWorks_Assembly/Harness_10-Emsamblaje.SLDASM
01_CAD/SolidWorks_Assembly/Acople de Robot.SLDPRT
01_CAD/SolidWorks_Assembly/Base.SLDPRT
01_CAD/SolidWorks_Assembly/Acople de Robot - Copy.SLDPRT

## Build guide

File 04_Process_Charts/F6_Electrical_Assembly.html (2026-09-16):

# Carta de proceso ilustrada

## F6 — Ensamble Eléctrico | Sistema Gripper Neumático

Plano CRP-RA09A-07 · ESP32 + Sensores + Actuadores · Norma ISO 9001:2015

1

EE-10

Recepción e inspección de componentes

Verificar contra lista BOM eléctrica:

- ESP32 (240 MHz WiFi/BT)
- Fuente 24 VDC / 5 A + fusible F1 3 A
- LM2596 (24→5 V) y AMS1117-3.3
- MPX5700, vacuostato PNP, IRF540N, K1 5 V

Norma: ISO 9001 cl. 8.4

Control: Visual + multímetro

Registro: QC-EE-001

▼

2

EE-20

Montaje de fuente y rieles de alimentación

Instalar fuente 24 VDC/5 A con fusible F1 = 3 A en línea +24 V. Cablear rieles principales:

- Riel 24 VDC (rojo)
- Riel GND (negro común)

Tensión: 24 VDC ±5%

Fusible: 3 A vidrio

Cable: AWG 18 mín.

▼

3

EE-30

Step-down 24 V → 5 V → 3.3 V

Instalar conversores en serie:

- LM2596: 24 V → 5 V (ESP32 / relé K1)
- AMS1117-3.3: 5 V → 3.3 V (lógica ESP32)

Ajustar potenciómetro del LM2596 antes de conectar carga.

5 V output: 5.00 V ±0.1

3.3 V output: 3.30 V ±0.05

Verificar: sin carga primero

▼

4

EE-40

Montaje del controlador ESP32

Fijar ESP32 a placa/PCB. Conectar:

- 3.3 V y GND a rieles
- Reservar GPIOs: 34/35 (ADC), 26/27 (OUT), 21/22 (I²C)
- TX0/RX0 libres para depuración serial

Vcc: 3.3 V (NO 5 V)

GPIO ADC: 34, 35

GPIO OUT: 26, 27

I²C: SDA=21 / SCL=22

▼

5

EE-50

Cableado de sensores con divisor de tensión

MPX5700 (0–700 kPa, 0–5 V) → divisor R1=10k / R2=4k7 → GPIO35.
Vacuostato PNP 24 V → divisor R3=10k / R4=4k7 → GPIO34.
Crítico: divisores protegen entradas ADC del ESP32 (máx. 3.3 V).

R1, R3: 10 kΩ ¼ W

R2, R4: 4.7 kΩ ¼ W

V salida divisor: ≤ 3.3 V

¡No omitir divisor!

▼

6

EE-60

Etapa de potencia: MOSFET + Relé K1

Cablear etapa de actuación desde GPIO26:

- Rg=220 Ω en gate del IRF540N
- Rgs=10 k pull-down gate-source
- Bobina relé K1 (5 V) entre drain y +5 V; diodo D1 volante
- Contacto NA del K1 conmuta la electroválvula 24 V

Q1: IRF540N (Vgs=3.3 V OK)

Rg: 220 Ω / Rgs: 10 k

D1, D2: 1N4007

D1 obligatorio (FCEM)

▼

7

EE-70

LED indicador y bus I²C

GPIO27 + R5=220 Ω + LED verde (señal "vacío OK").
I²C al robot CRP-RA09A-07: SDA=GPIO21, SCL=GPIO22 con resistencias pull-up R6=R7=4k7 a 3.3 V.

R5: 220 Ω

R6, R7: 4.7 kΩ pull-up

I²C: 100/400 kHz

Bus: 3.3 V lógica

▼

8

EE-80

Verificación previa al energizado

Con multímetro en modo continuidad, verificar:

- Sin cortocircuitos +24 V ↔ GND, +5 V ↔ GND, +3.3 V ↔ GND
- Polaridad de electrolíticos y diodos
- Aprietes y aislamientos en puntos de potencia

Test: Continuidad / Diodo

Acción: ANTES de energizar

Registro: QC-EE-002

⚠ No omitir esta etapa

▼

9

EE-90

Energizado y verificación funcional

Energizar progresivamente y medir tensiones:

- +24 VDC en bornes fuente
- +5 VDC salida LM2596
- +3.3 VDC salida AMS1117

Cargar firmware ESP32; verificar lectura ADC y conmutación K1.

+24 V: 24.0 ± 0.5 V

+5 V: 5.00 ± 0.10 V

+3.3 V: 3.30 ± 0.05 V

✓ ESP32 activo

▼

10

EE-100

Inspección final y liberación eléctrica

Pruebas funcionales:

- Lectura ADC MPX5700 estable y dentro de rango
- Conmutación GPIO26 → MOSFET → K1 → electroválvula audible
- LED encendido cuando vacío ≥ −0.6 bar
- Comunicación I²C con robot OK

Firma del responsable. Registro QC-EE-003.

Norma: ISO 9001 cl. 8.6

Resultado esperado: 100 % OK

Ensamble eléctrico LIBERADO

Resultado

Tablero eléctrico
del Sistema Gripper Neumático
listo y verificado

Controles clave

- ⚡ Riel 24 V / 5 V / 3.3 V verificados
- 🔌 Fusible F1 = 3 A en línea +24 V
- 📐 Divisores R1=10k / R2=4k7 (ADC)
- 🔁 MOSFET IRF540N + Rg=220 Ω + Rgs=10 k
- 🛡️ Diodos D1 / D2 1N4007 (volante)
- 🔗 Pull-ups I²C R6=R7=4k7 a 3.3 V
- 💡 LED señal "vacío OK" en GPIO27
- ✅ Sin cortos: 24 V / 5 V / 3.3 V → GND

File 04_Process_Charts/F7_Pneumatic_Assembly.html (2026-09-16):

# Carta de proceso ilustrada

## F7 — Ensamble Neumático | Sistema Gripper Neumático

Venturi VN-10-H FESTO · 4 ventosas Ø25 mm · Norma ASME B31.3 / ISO 9001:2015

1

EN-10

Recepción e inspección de componentes neumáticos

Verificar contra BOM neumática:

- Generador vacío Venturi VN-10-H
- Electroválvula 5/2 vías 24 VDC
- 4 ventosas NBR Ø25 mm tipo fuelle
- Manifold 1 entrada / 4 salidas, racores G1/8", T-conexión
- Tubería poliuretano Ø6 mm + cinta PTFE

Norma: ISO 9001 cl. 8.4

VN-10-H: P 4–6 bar

Vacío teórico: ≤ −0.85 bar

Registro: QC-EN-001

▼

2

EN-20

Prueba previa del generador VN-10-H

En banco de pruebas: conectar VN-10-H a aire comprimido 4–6 bar (con FRL: filtro/regulador/lubricador). Medir vacío en boca de aspiración con vacuómetro calibrado.
Criterio: vacío alcanzado ≥ −0.60 bar (mín. funcional).

P entrada: 4–6 bar

Vacío mín.: −0.60 bar

Norma: ISO 8573-1

Registro: QC-EN-002

▼

3

EN-30

Preparación de roscas con cinta PTFE

Aplicar cinta PTFE a todos los racores roscados:

- 2–3 vueltas en sentido del apriete
- NO cubrir la 1ª rosca (evita contaminación interna)
- Sin arrugas ni burbujas

Aplica a racores G1/8", T-conexión, racores 3/8"-16 UNF.

Cinta: PTFE 12 mm

Vueltas: 2 a 3 (sentido rosca)

Norma: ASME B31.3

▼

4

EN-40

Corte de tubería neumática Ø6 mm

Cortar tubería de poliuretano Ø6 mm en tramos:

- 4 tramos ~ 100 mm (manifold/T → ventosas)
- 2–3 tramos ~ 80 mm (electroválvula → venturi → T)

Usar cortador de tubo (no tijera). Corte recto, sin rebaba interna.

Diámetro: Ø6 mm exterior

Material: poliuretano

Tolerancia: ±2 mm long.

Sin rebaba (sello racor)

▼

5

EN-50

Montaje de ventosas en base

Instalar 4 ventosas Ø25 mm fuelle en los brazos de la Base de Ventosas:

- Insertar vástago en agujero Ø5 mm
- Fijar con tuerca de retención (apriete manual + ¼ vuelta)
- Fuelle hacia abajo / exterior

Tipo: NBR fuelle

Diámetro: Ø25 mm

Apriete: manual + ¼ vuelta

⚠ No forzar rosca

▼

6

EN-60

Instalación del Venturi VN-10-H y electroválvula

Montar el generador VN-10-H en alojamiento Ø44.47 mm del Acople Superior. Instalar electroválvula 5/2 vías 24 VDC en la línea de alimentación entre la fuente de aire y el venturi.
Verificar orientación de puertos: P (entrada), V (vacío) y E (escape).

VN-10-H: Ø44.47 mm

EV: 5/2 vías, 24 VDC

Aire: seco, filtrado

Norma: FESTO Manual

▼

7

EN-70

Conexión del manifold y T-conexión

Instalar T-conexión 1/8" en el puerto de vacío del VN-10-H. Conectar 2 racores rectos G1/8" a la T y enlazar al manifold (1 entrada / 4 salidas) que distribuye vacío hacia las 4 ventosas en paralelo.

Manifold: 1 IN / 4 OUT

Racores: G1/8" niquelados

Tubería: Ø6 mm hasta tope

Verificar: click audible

▼

8

EN-80

Instalación del vacuostato

Montar vacuostato PNP 24 VDC en derivación del circuito de vacío (lado manifold o T-conexión). Ajustar setpoint de conmutación a −0.6 bar. Cablear señal de salida hacia GPIO34 del ESP32 (vía divisor R3/R4).

Setpoint: −0.60 bar

Tipo: PNP 24 VDC

Salida: a GPIO34 (con divisor)

Función: feedback al ESP32

▼

9

EN-90

Prueba de estanqueidad neumática

Conectar línea a 4 bar. Aplicar solución jabonosa en TODAS las uniones (T, racores, manifold, electroválvula, ventosas).
Observar durante 60 s. Sin burbujas = aprobado. Si hay fuga: apretar / reemplazar / repetir prueba.

P prueba: 4 bar

Tiempo: 60 s

Norma: ASME B31.3

Registro: QC-EN-003

▼

10

EN-100

Prueba funcional de vacío y sujeción

Energizar electroválvula y conectar aire a 5 bar. Verificar:

- Vacío ≥ −0.60 bar en circuito (vacuómetro)
- Vacuostato conmuta y enciende LED de "vacío OK"
- 4 ventosas sostienen pieza plana de 500 g ≥ 30 s

P entrada: 5 bar

Vacío req.: −0.60 bar

Carga: 500 g por ≥30 s

Test funcional aprobado

▼

11

EN-110

Inspección final y liberación neumática

Revisión final completa del subsistema neumático: tubería sin dobleces, racores limpios, vacuostato calibrado, ausencia de fugas, prueba funcional aprobada. Completar registro de trazabilidad QC-EN-004 y firmar liberación.

Norma: ISO 9001 cl. 8.6

Resultado: 100 % OK

Subsistema neumático LIBERADO

Resultado

Subsistema Neumático del
Sistema Gripper ensamblado y
verificado funcionalmente

Controles clave

- 💨 P entrada: 4 – 6 bar (FRL)
- 📉 Vacío ≥ −0.60 bar (mín. funcional)
- 🧪 Estanqueidad 4 bar / 60 s sin burbujas
- 🏋️ Sostiene 500 g / ≥30 s con 4 ventosas
- 🌀 Cinta PTFE: 2–3 vueltas, 1ra rosca libre
- 🔧 Tubería Ø6 mm hasta tope (click)
- ⚡ Vacuostato: setpoint −0.60 bar
- ✨ Sin dobleces ni rebabas internas

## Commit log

2026-09-16 Add project files: CAD, STL, documentation, process charts and spreadsheets
    [Acople de Robot - Copy.SLDPRT, Acople de Robot.SLDPRT, Base.SLDPRT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]
2026-09-24 Add SolidWorks assembly render to README
